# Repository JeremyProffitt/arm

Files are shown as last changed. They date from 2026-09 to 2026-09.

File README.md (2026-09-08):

# LUMA — printable robotic desk companion

<p align="center">
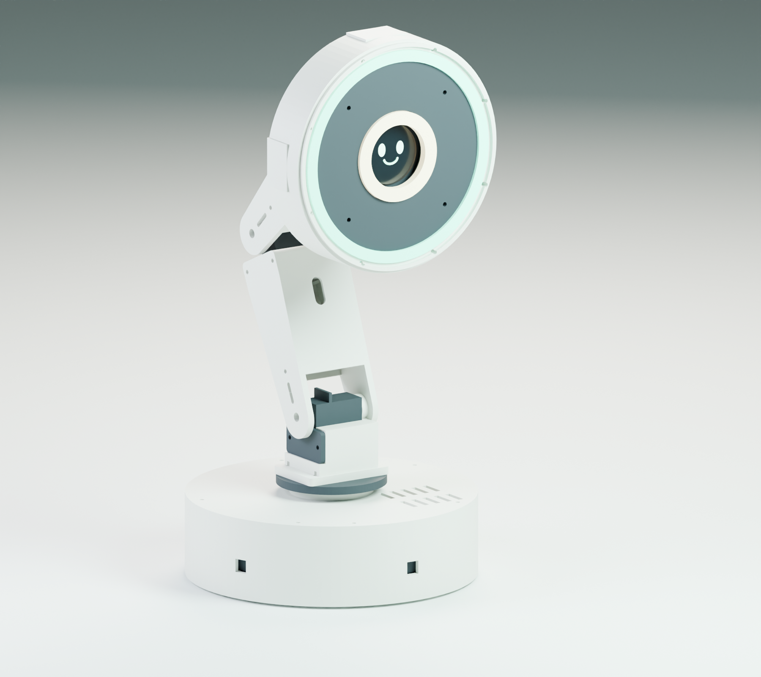
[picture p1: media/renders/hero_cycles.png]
LUMA robotic desk companion hero render
  
</p>

<p align="center"><em>A little light. A little motion. A lot of personality.</em></p>

Open [START_HERE.html](START_HERE.html) for the illustrated project browser and three promotional videos. The complete build reference is [LUMA_Assembly_Manual.pdf](deliverables/LUMA_Assembly_Manual.pdf).

This original prototype is inspired by the [Autonomous Lamp](https://www.autonomous.ai/lamp). It has a Raspberry Pi4 master, four inventory Miuzei DS3218MG joints controlled by a PCA9685, five Adafruit VL53L1X STEMMA QT sensors mounted inside the pedestal wall, a circular animated display, a white light ring, and a larger RGB halo.

Revision C (7 September 2026) moves all five sensors into direct four-screw mounts behind pedestal apertures. It replaces the former bus servos with the on-hand DS3218MG 270° units, widens the enclosed links for single-horn/625-bearing joints, and adds PCA9685 PWM plus a regulated6V servo rail. The standard head uses the **Waveshare ESP32-S3-Touch-LCD-1.85, SKU 28514**. The optional head uses the **Waveshare 4inch DSI LCD (C)** driven directly by the Pi.

## Meet LUMA

Click a scene to watch the full animation.

<p align="center">
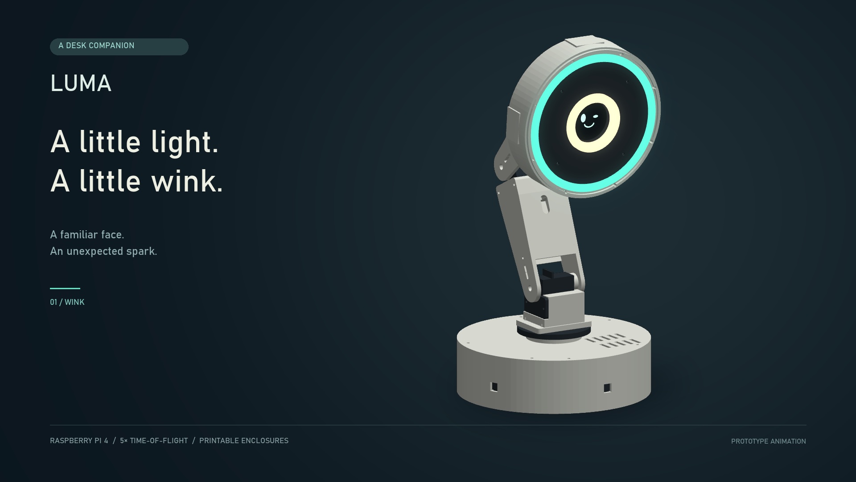
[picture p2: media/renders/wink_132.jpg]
LUMA winking
  
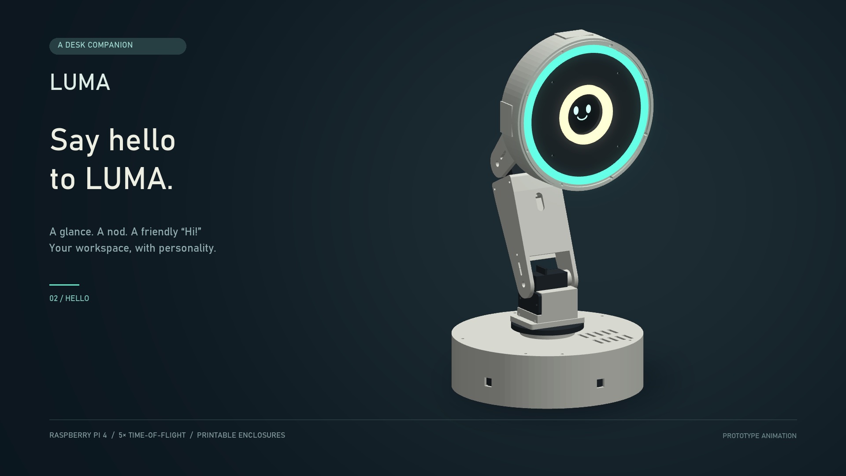
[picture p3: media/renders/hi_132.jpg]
LUMA saying hello
  
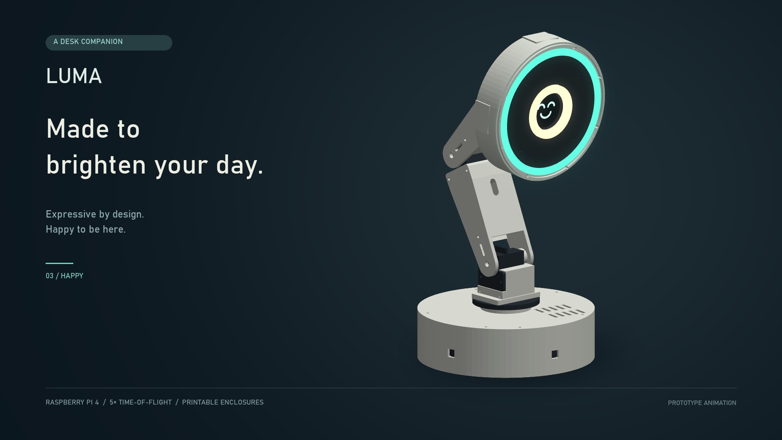
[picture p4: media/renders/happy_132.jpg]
LUMA showing a happy expression
  
</p>

<p align="center"><sub>Wink · Say hello · Happy</sub></p>

## Designed to be built

<p align="center">
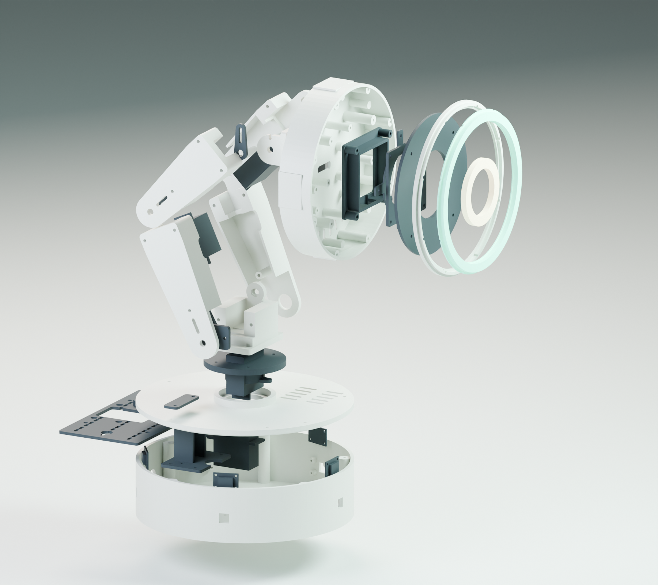
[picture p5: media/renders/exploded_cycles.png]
Exploded render of LUMA's printable structure and electronics
  
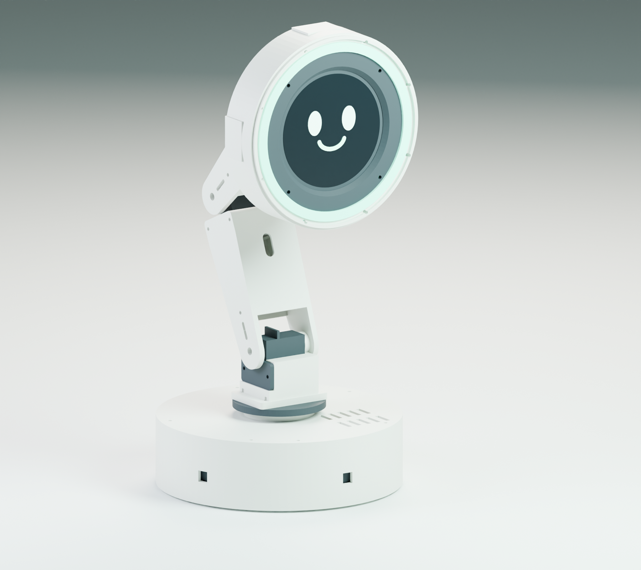
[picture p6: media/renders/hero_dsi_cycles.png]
LUMA with the optional four-inch DSI display head
  
</p>

<p align="center"><sub>Exploded standard assembly · Optional four-inch DSI display head</sub></p>

<p align="center">
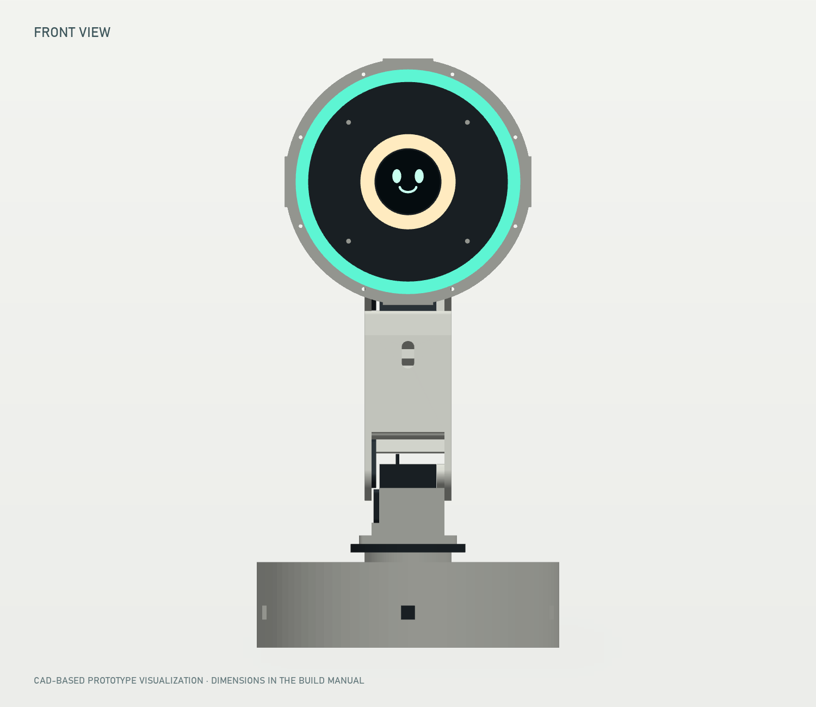
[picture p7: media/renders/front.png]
Front orthographic view of LUMA
  
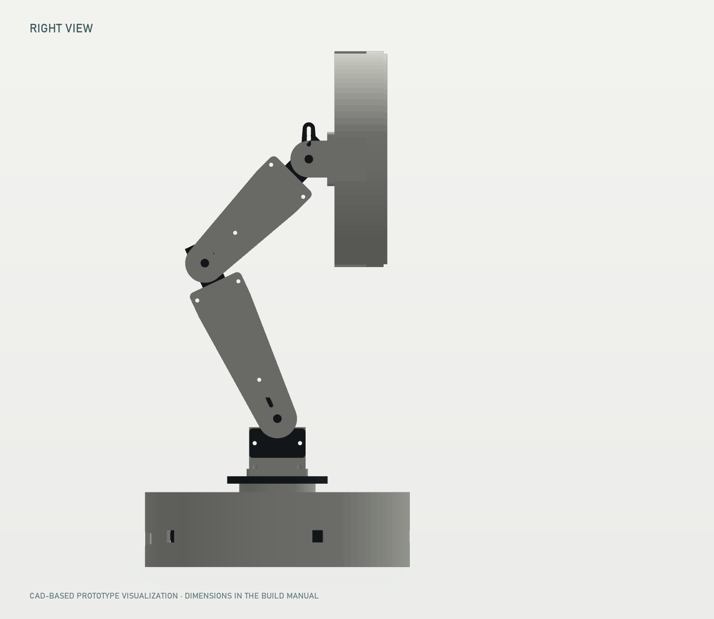
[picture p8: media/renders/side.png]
Right orthographic view of LUMA
  
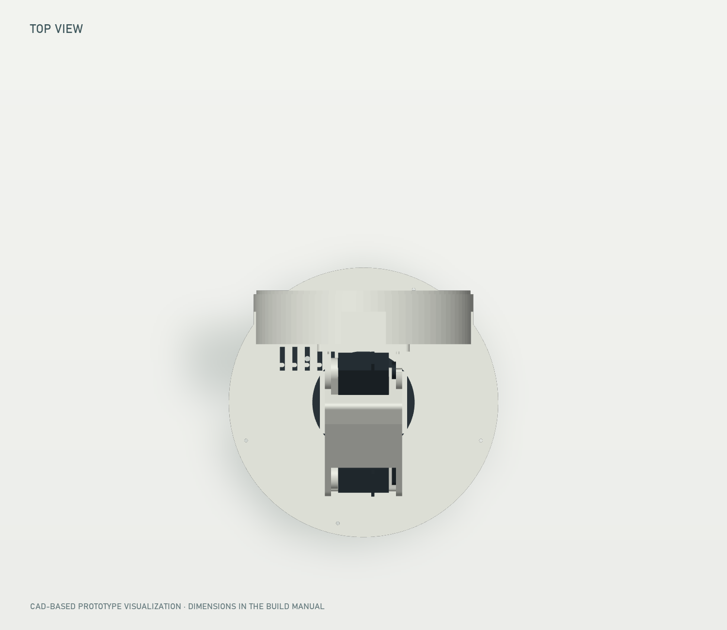
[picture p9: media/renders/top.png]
Top orthographic view of LUMA
  
</p>

## Deliverables

| File or folder | Contents |
| --- | --- |
| `deliverables/LUMA_Assembly_Manual.pdf` | Illustrated instructions, BOM, wiring, calibration, verification worksheet and engineering sheets |
| `deliverables/LUMA_Engineering_Drawings.pdf` | Standalone A3 drawing set, with model-derived views and interface dimensions, including the optional head sheet |
| `deliverables/LUMA_Purchased_Parts.csv` | Consolidated purchased parts, quantities, supplier links and budget allowances (`D` rows are the optional head) |
| `deliverables/LUMA_Print_Schedule.csv` | Printable part quantities, materials, orientations and variant (`standard` or `dsi-head`) |
| `cad/stl/` | Individual printable STL files, in millimeters |
| `cad/luma.scad`, `cad/build.py` | Editable parametric source and export script |
| `cad/assembly.scad`, `cad/assembly_dsi.scad` | Open in OpenSCAD for the complete assembled model, standard or optional head |
| `cad/assembly.json`, `cad/assembly_dsi.json` | Exact assembly placements, articulation axes and indexed neutral pose |
| `cad/ballast_plate.dxf`, `cad/ballast_plate.svg` | Steel ballast profile and dimensioned drilling template |
| `cad/visual_only/` | Purchased-component envelopes for visualization; do not print these |
| `electronics/` | Electrical architecture, wiring diagram, pin-to-pin CSV and source BOM |
| `software/` | Pi controller, simulation, tests, setup, exact-board face firmware and the Pi-rendered face for the DSI head |
| `media/videos/01_wink.mp4` | Winking promotional animation |
| `media/videos/02_hi.mp4` | Greeting promotional animation with spoken “Hi!” |
| `media/videos/03_happy.mp4` | Happy promotional animation |
| `media/renders/` | Finished, exploded, orthographic and promotional images, plus `hero_dsi.png` for the optional head |
| `media/sources/` | Editable rendering and animation sources |
| `validation/` | Mesh/intersection, software, PDF and video verification records |
| `plan.md` | Revision C work plan and execution log |

`deliverables/LUMA_Complete_Project.zip` is the portable archive. Extract it before opening the HTML index. Development tool downloads, virtual environments and intermediate previews are excluded. The archive contains a SHA-256 inventory.

`deliverables/LUMA_Printable_STLs.zip` is the smaller print-only download, including the quantity schedule and printing notes. Consult the assembly manual before printing or purchasing parts.

## Before printing

Read the mechanical assembly chapter and exact part list. Print the fit coupon first. The largest base parts have a 216 mm footprint, so a 220 mm bed needs careful placement and little or no brim; a larger bed provides more margin. Structural parts use PETG. Both light covers use natural translucent PETG, with a thin solid face that can be lightly frosted after printing. Each arm link is a left and a right half; print both, plate-down, and assemble the servo and harness inside before closing the link.

The initial folded pose reduces reach: upper link115° and forearm45° above+Y, head facing+Y. Center one unloaded DS3218 at a time before installing its horn. Motion commands are small offsets around this pose. The uncalibrated default does not arm the motors, and PCA9685 communication does not prove shaft position.

The full STL assemblies are for viewing. Print the individual files and apply the schedule quantities. Purchased bearings, metal servo horns, steel ballast, electronics and fasteners are not printed replacements. The optional4-inch head prints three variant files and omits six standard-head files; the schedule lists both sets.

## Run the simulator

Python 3.11 or newer is sufficient; no Pi hardware is activated:

```console
cd software
python -m luma.app --scene wink
python -m luma.app --scene hi
python -m luma.app --scene happy
python -m unittest discover -s tests -v
```

The simulator prints timestamped expression, light and pose events. The software README gives the separate Raspberry Pi installation, display firmware build, the optional DSI-head display setup and supported first-motion procedure.

## Rebuild documents and checks

Create a Python environment and install `docs/requirements.txt`. Install OpenSCAD for the CAD exports; consult `cad/build.py` and the mechanical notes for platform paths and selectors. The media README describes the video/rendering dependencies.

From the project root, once the CAD, media and source chapters are present:

```console
python cad/build.py
python cad/check_purchased_fit.py
python validation/check_assembly.py
python docs/build_bom.py
python media/sources/render_media.py --stills
python media/sources/render_media.py --manifest cad/assembly_dsi.json --suffix _dsi --stills --views hero
python docs/build_drawings.py
python docs/build_manual.py
python validation/verify_project.py
python docs/package_project.py
```

The static intersection check compares assembled printed solids at the indexed neutral pose for both assemblies. It does not certify the full motion envelope, purchased hardware fit, wiring clearance, strength, balance or temperature. The final verification report distinguishes executed digital checks from untested hardware and records the display cross-compilation status separately.

## Release status

Revision C is a digital prototype, not a physically built or certified product. The promotional clips are rendered animations. Physical horn/bearing fit, supported commissioning, load/stability checks, regulated6V behavior and thermal/optical measurements remain first-build work. The DS3218 servos provide no readable position/current/temperature feedback. No measured lumen/CRI output or autonomous collision-avoidance capability is claimed. The optional head's800mm DSI cable remains a bench-verification item.

Vendor specifications and third-party display initialization provenance are linked in the manual and firmware notices. The appearance-reference image used during research is not redistributed in the package.

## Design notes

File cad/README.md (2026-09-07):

# LUMA CAD files

Open `assembly.scad` in OpenSCAD to view the entire assembled lamp with the standard 1.85-inch head, or `assembly_dsi.scad` for the optional 4-inch DSI head. Both import the supplied meshes with the positions and colors in `assembly.json` / `assembly_dsi.json`; `assembly_preview.scad` is an equivalent copy of the standard preview. Edit individual part geometry in `luma.scad` and select its `part` parameter using an ID from `part_manifest.json`.

Print the standard build from the24 files in `stl/` whose manifest `variant` is `standard`, in the quantities from `part_manifest.json`. The optional4-inch DSI head adds `head_shell_dsi`, `lcd4_carrier` and `face_ring_dsi`, and omits `head_shell`, `face_center`, `white_carrier`, `inner_diffuser`, `lcd_cradle` and `lcd_retainer`. Revision C has no printable sensor pods, retainers or brow bracket: all five Adafruit3967 boards screw directly to bosses inside the pedestal wall. The four arm halves print plate-down, and the head fork prints on its mounting plate rotated180 degrees aboutX. Do not print anything from `visual_only/`; it contains purchased-component envelopes and complete assembled references.

The exact OpenSCAD executable location defaults to `C:/Program Files/OpenSCAD/openscad.com`; override it with the `OPENSCAD` environment variable if needed. Run `python cad/build.py` from the project root with NumPy and trimesh installed to regenerate every asset, or `python cad/build.py upper_arm_left forearm_left` to re-export only the named parts. The hidden electronics tray uses 32 facets to keep exports practical; all dimensions remain the same. `cad/refresh_validation.py` measures existing STLs without re-exporting them.

`ballast_plate.dxf` contains a 180 mm steel disc outline and eight drill circles in millimetres. Its thickness is 6 mm; the DXF is 2D, not an instruction to print the ballast. The dimensioned SVG drill template is on a 250 x 230 mm page, suitable for an actual-size A3 print.

`validation.json` records mesh integrity, connected bodies, dimensions and solid volume. `purchased_fit.json` checks conservative DS3218MG, pedestal-sensor and display envelopes in both assemblies; `../validation/assembly_check.json` records printed-part intersections at indexed neutral. These reports do not replace a physical horn/bearing fit, load, electrical, thermal or moving-clearance test.

`mechanical.md` provides the assembly instructions and assumptions. `bom_mechanical.csv` lists metal, three625 idler bearings, hardware and printing consumables. Rows starting with `D` belong to the optional head. The complete BOM also includes the inventory DS3218MG servos, user-selected PCA9685 and6V regulator. Vendor geometry sources are identified in `docs/sources.json`.

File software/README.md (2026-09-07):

# LUMA Pi4 controller and face firmware

The project includes a deterministic simulator and Raspberry Pi adapters for five pedestal ranging sensors, four Miuzei DS3218MG servos through a PCA9685, two independent LED rings, USB face display and local spoken Hi. The simulation needs Python3.11 or later.

```console
cd software
python -m luma.app --scene wink
python -m luma.app --scene hi
python -m luma.app --scene happy
python -m unittest discover -s tests -v
```

Simulation prints timestamped pose/light/face events as JSON. It advances deterministically without sleeping. `--seconds` sets duration. Scenes last6seconds, then return to idle. The three promotional scenes remain within the initial CAD travel envelope; they are repeatable face/motion scripts and do not require a cloud service.

## Raspberry Pi installation

Use Raspberry Pi OS Bookworm64bit on Pi4. The following setup commands affect only a Pi used for this project; do not execute them on the development Windows computer.

```console
sudo apt update
sudo apt install python3-venv python3-pip python3-dev i2c-tools espeak-ng alsa-utils
sudo raspi-config
```

In Interface Options enable I2C and SPI. In `/boot/firmware/config.txt`, confirm `dtparam=i2c_arm=on`, `dtparam=i2c_arm_baudrate=100000`, and `dtparam=spi=on`. Set `dtparam=audio=off` because BCM18's PWM peripheral drives theRGBW ring and analog audio conflicts. USB audio is separate. Reboot after these settings.

```console
cd software
python3 -m venv .venv
.venv/bin/pip install -e '.[hardware]'
ls -l /dev/serial/by-id/
aplay -l
```

Enter the actual display `/dev/serial/by-id/` path in `config.json`. The PCA9685 is I2C address64 (`0x40`), with yaw/shoulder/elbow/wrist on channels0/1/2/3. Select the USB speaker as the ALSA output or set `audio_device` to the identifier from `aplay -L`. The standard display and speaker share Pi4 USB power; use a powered hub if measurement requires it. Motors and LEDs never take power from Pi USB or GPIO.

Before connecting motor power, test the sensor chain and display independently. These commands do not instantiate the PCA9685 or LED drivers and do not require calibrated joints:

```console
.venv/bin/python -m luma.bench sensors --seconds 10
.venv/bin/python -m luma.bench display --port /dev/serial/by-id/YOUR_DISPLAY_DEVICE --scene all --seconds 10
```

The sensor check reports millimeters, age and mux channel in front/front-left/rear-left/rear-right/front-right order. Present a matte target at each pedestal aperture. `near` means a valid value below100mm: communication can pass, but armed motion would fault. The display check cycles idle/wink/Hi/happy and checks firmware replies. Inspect the pixels yourself. Exit status0 is pass,1 fail and130 interrupted. I2C normally needs membership in the `i2c` group; USB serial normally needs `dialout`.

Center only one disconnected, unloaded servo at a time. Keep its straight horn off the arm and keep the physical stop in reach. The command is capped at10seconds, disables the other three PCA9685 channels, and removes the selected PWM pulse when it exits:

```console
.venv/bin/python -m luma.bench servo --joint yaw --pulse-us 1500 --seconds 2 --confirm-unloaded
```

Repeat with `shoulder`, `elbow` and `wrist`. Power off before installing each horn. The DS3218 datasheet gives500-2500µs over270° with1500µs nominal neutral. Record the actual mechanical neutral in `neutral_pulse_us`; do not use this command on a loaded joint.

The PWM-backed NeoPixel library normally requires root on Pi4, so the full hardware command uses the virtual environment interpreter with sudo. Leave `calibrated=false` while wiring/testing. Hardware mode without `--arm` requires PCA9685 communication but leaves all four PWM outputs disabled; the separate6V motor rail can remain off.

```console
sudo .venv/bin/python -m luma.app --hardware --scene hi --seconds 6
```

Complete the commissioning procedure in `../electronics/architecture.md`, including unloaded neutral indexing, polarity/sign checks, physical stop tests and five valid pedestal ranges. Only then set `calibrated=true`. Support the arm in its indexed pose before every armed start; software cannot read its physical angles:

```console
sudo .venv/bin/python -m luma.app --hardware --arm --scene happy --seconds 6
```

Any fault latches for that process. It stops new targets and leaves the PCA9685 at the last pulse widths. Inspect the reason, support the arm, remove the cause and restart explicitly. PCA9685 health proves I2C communication only, not servo movement or position. The physical motor stop removes6V holding power. There is no unattended boot or auto-arm service.

## Display firmware

`display_firmware/` targets **ESP32-S3-Touch-LCD-1.85 SKU28514 only**. It uses USB serial115200, an ST77916 QSPI controller on CS21/SCK40/D046/D145/D242/D341, and a TCA9554 at0x20 over SDA11/SCL10 for LCD resetEXIO2/P1. Backlight is GPIO5. This pin mapping is from the [Waveshare board documentation](https://docs.waveshare.com/ESP32-S3-Touch-LCD-1.85) and schematic. Firmware reads panel register0x04 and chooses one of the exact two vendor initialization tables: ID00-7F-7F-7F or00-02-7F-7F. Unknown IDs produce an error and do not advertise READY. Register command/data/delay values were converted from the vendor's April2025 demo to [Arduino_GFX](https://github.com/moononournation/Arduino_GFX/tree/v1.6.5) operations. A successful compile does not prove physical display operation; verify the purchased panel on the bench.

Install PlatformIO and build/flash the connected board:

```console
python -m pip install platformio
cd display_firmware
python -m platformio run
python -m platformio run --target upload --upload-port YOUR_SERIAL_PORT
python -m platformio device monitor --port YOUR_SERIAL_PORT --baud 115200
```

Commands are newline-delimited ASCII. `PING` replies `PONG`. `FACE idle`, `FACE wink`, `FACE hi`, `FACE happy`, and `FACE fault` reply `OK <name>`. Startup announces `READY LUMA1`. Invalid or overlong commands reply `ERR`. After1.5seconds without a host command/heartbeat the display shows WAITING. The host sends heartbeat every250ms and latches a motion hold if replies stop. No touch/audio/SD/battery functions are enabled on the display board; speech is generated on the Pi and played by the USB speaker.

## Optional 4-inch DSI head (Pi-rendered face)

Instead of the ESP32 face board, LUMA can use a Waveshare 4inch DSI LCD (C) — a round720x720 panel wired directly to the Pi's DSI port. There is no coprocessor for this head: the Pi itself renders the face every frame with `luma/face.py`, which reproduces `paint()` from `display_firmware/src/main.cpp` in Python (same colors, same shapes, same scene timing) scaled from the firmware's360x360 canvas up to the panel's720x720 resolution.

Select this head by setting `"display_kind": "dsi"` in `config.json` (leave `display_port` alone; it is ignored for this kind). Install the extra dependency alongside the existing hardware group:

```console
.venv/bin/pip install -e '.[hardware,dsi]'
```

Add these lines to `/boot/firmware/config.txt` for the Waveshare4inch DSI LCD(C):

```
dtoverlay=WS_xinchDSI_Screen,SCREEN_type=10,I2C_bus=10
dtoverlay=WS_xinchDSI_Touch,I2C_bus=10
```

Both overlays are the vendor's documented setup; LUMA's software never reads touch events — the lamp has no touch-driven behavior. If the picture is upside down for the mounted orientation (connectors at the bottom), rotate it with the vendor's documented `display_lcd_rotate`/Wayland rotation setting rather than in LUMA.

Running outside a desktop session (the normal case for an unattended lamp) needs pygame's KMS/DRM backend. `sudo` drops environment variables, so pass the driver through `env`:

```console
sudo env SDL_VIDEODRIVER=kmsdrm .venv/bin/python -m luma.app --hardware --scene hi --seconds 6
```

Bench-check the head on its own, the same way as the USB face board:

```console
.venv/bin/python -m luma.bench display --kind dsi --scene all --seconds 10
```

`--port` is not required (and is ignored) when `--kind dsi`; it stays required for the default `--kind usb_serial`. There is no serial heartbeat to a coprocessor for this head, so `Hardware`/`bench.display`'s notion of "heartbeat" becomes "a frame was drawn within the last1.5seconds" — `DsiDisplay.update()` returns that boolean the same way `Display.update()` returns the USB PONG heartbeat, so the rest of the control/fault-latching logic in `luma/control.py` is unaffected by which head is attached.

## Source/verification notes

`luma/servo_pwm.py` uses the maintained Adafruit CircuitPython PCA9685 library at50Hz. It converts calibrated angles through the DS3218's documented500-2500µs/270° range, starts with all four outputs disabled, and checks controller registers over I2C. The bounded bench path enables one unloaded channel only. Tests cover the duty conversion, channel isolation, config validation, scene limits, five renamed sensor inputs and fault behavior. Hardware paths have not been exercised on a physical Pi/arm.

The pinned firmware toolchain is self-contained in `platformio.ini`; downloaded SDK/toolchain caches are development artifacts and do not need redistribution. Python hardware dependency versions are bounded for installation flexibility, not a physical acceptance-tested lockfile. Record actual installed versions with `pip freeze` when commissioning the Pi.

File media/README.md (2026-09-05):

# LUMA promotional media

Three 9-second films show the proposed lamp winking, greeting the viewer with an
audible “Hi!”, and moving happily. Each final MP4 is 1920 × 1080, H.264 with AAC
stereo sound and actual 24 fps CAD animation. A restrained camera push brings
each expression closer while keeping the titles stable.

These are **prototype animations**, not footage of a built or tested device.
All mechanical surfaces are rendered from the project's assembly STL files;
the screen graphics, illumination and motion are illustrative. No AI concept
images, stock footage, external music or unlicensed character assets are used.

## Rebuild

Install Python 3.13, Pillow, NumPy, ModernGL and imageio-ffmpeg. Generate the CAD
assembly first, then run from the project directory:

```powershell
python -m pip install -r media/requirements.txt
powershell -ExecutionPolicy Bypass -File media/sources/synthesize_hi.ps1
python media/sources/render_media.py --stills --clip all
```

The speech source uses the installed Windows Microsoft Zira Desktop voice.
The greeting WAV is included so rebuilding the films does not require Windows
speech synthesis. Original sound-design tones are synthesized by the renderer.

`sources/render_media.py` is the editable scene, camera, lighting, motion,
face-animation, typography and sound source. The assembly JSON supplies the
manufactured geometry and kinematic pivots. The final films use a depth-buffered
OpenGL renderer with 4× antialiasing. A basic software renderer is included as a
fallback. Blender is optional, via `sources/blender_stills.py`, for physically
lit still images.

The supplied hero and exploded `.blend` files use Blender 4.5.9 LTS. That optional
portable application was downloaded from the official Blender release archive
and verified against its published SHA-256 checksum. It is not included in the
project ZIP. Run `blender -b -P media/sources/blender_stills.py` to rebuild those
images, then use the resulting `*_cycles.png` files in the manual.

`renders/hero.png`, `exploded.png` and three orthographic PNGs support the PDF
manual. `renders/hero_dsi.png` shows the optional 4-inch DSI head; make it with
`python media/sources/render_media.py --manifest cad/assembly_dsi.json --suffix _dsi --stills --views hero`
(or `blender -b -P media/sources/blender_stills.py -- --manifest cad/assembly_dsi.json --suffix _dsi --hero-only`
for the physically lit version). The face graphics scale with the active display
radius in the assembly JSON. `renders/promotional_contact_sheet.jpg` samples the
films. `videos/` contains the deliverable MP4s; `audio/` contains the original and
mixed sound.

The `.tools/` directory, if present, is only a local dependency cache and is not
part of the design deliverables.

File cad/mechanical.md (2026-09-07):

# LUMA mechanical assembly, revision C

The editable geometry is `cad/luma.scad`. `cad/build.py` exports printable parts, two assembly manifests, purchased-part envelopes, and mesh measurements. Open `cad/assembly.scad` for the standard head or `cad/assembly_dsi.scad` for the optional4-inch DSI head. Files under `cad/visual_only` are not printable parts.

Revision C moves all five Adafruit3967 VL53L1X boards from external head pods to direct mounts behind the pedestal wall. It removes the pod, retainer, and DSI brow-bracket parts and closes the old head penetrations. It also replaces four dual-output ST3215 bus servos with four inventory Miuzei DS3218MG 270-degree PWM servos. The links and yoke are wider, each pitch joint has a625 bearing opposite its single driven horn, and the pedestal/yaw stack is6mm taller. Link pitches, indexed angles, displays, and light-ring geometry remain unchanged.

The indexed neutral has the upper link115° and forearm45° counterclockwise from forward+Y. The relative elbow angle is−70°. Pitch axes run alongX and yaw runs alongZ. Dimensions are: base diameter216mm and wall height56mm; shoulder axisZ121mm; upper pitch140mm; forearm pitch120mm; head diameter176mm and optical depth42mm. The rear head plane center is aboutY46.7mm/Z332.7mm, and the housing top is about420.7mm. Rubber feet add5mm.

## Purchased geometry and fit datums

The Miuzei DS3218 datasheet specifies a40 × 20 × 40.5mm body, 4.8-6.8V PWM control, and a300mm lead. The model uses a conservative body envelope fromX−30..10 relative to the shaft, Y±10, and Z−40.5..0 from the output-side case plane. The mounting-tab envelope is54.5mm long at the datasheet's27.7mm height datum. The included straight metal arm and25T spline stay purchased parts. Its attachment-hole positions and thread are not dimensioned, so the printed driven interfaces use a7mm center clearance and two3.4mm radial slots at12-18mm and20-25mm. Measure the actual horn before selecting bolts. Source: https://images-na.ssl-images-amazon.com/images/I/81Lbgu%2BnG6L.pdf .

Each pitch joint is supported on both sides. The driven plate attaches to the straight metal servo arm through a3.3mm printed spacer. The opposite plate carries a625-2RS bearing, 5mm bore ×16mm OD ×5mm wide. An M5 precision-shank or shoulder bolt clamps only the bearing inner race to a captive M5 nut in the parent idler boss. Use thin thrust washers that do not touch the outer race. The yaw platform remains independently supported by one6808-2RS bearing, 40 ×52 ×7mm.

The Adafruit3967 board outline and four plated holes come from Adafruit's Eagle board file. The board is25.40 ×17.78mm. Its2.5mm holes form a20.32 ×12.70mm pattern centered on the optical package. The pedestal uses four6mm bosses with2.1mm blind pilots per board. The board's component face points outward and its sensor looks through a10 ×10mm open wall aperture. Source: https://github.com/adafruit/Adafruit-VL53L1X-PCB .

The standard display remains the55 ×55mm Waveshare ESP32-S3-Touch-LCD-1.85. It uses a55.8mm edge pocket and foam shims; no guessed board holes. The optional Waveshare4inch DSI LCD(C) remains a round720 ×720 panel in aØ126mm case with four M4 bosses on a75 ×75mm square. Its controller-board/connector envelope is measured from the vendor STEP. Verify every purchased connector and glass projection before tightening.

## Print settings and fit coupon

Print all units in millimeters at100%. The216 ×216mm base leaves only2mm per edge on a220mm bed. Use PETG,0.20mm layers, four walls for general parts, and six walls/40% gyroid for the four link halves and joint supports. The link halves print with their5mm outer plates on the bed. The head yoke prints on its rear mounting plate, rotated180° aboutX, with supports under the fork ears. The removed sensor pods, retainers, and brow bracket are not part of revision C.

Print `fit_coupon` first. It carries3.0/3.2/3.4/3.6mm bores, the16.2mm 625 pocket, and the DS3218 straight-horn slots. Tune only the affected CAD clearance; never scale the full mechanism. A625 bearing must seat squarely without force through its inner race. Clear through-holes by hand. The2.1mm base sensor and Pi pilots are for carefully started M2.5 screws. Do not force a screw or bend a PCB.

Print the light diffusers in natural/translucent PETG at0.15mm layers, three perimeters, and100% infill. Preserve the1.2mm optical skin. Do not put printed plastic, frosting, adhesive, or an untested IR window over any ToF aperture.

## Prepare metal parts

1. Make theØ180 ×6mm mild-steel ballast from `cad/ballast_plate.dxf` or the dimensioned SVG. Drill fourØ4.4 holes at(±45,±35) and fourØ3.4 holes at(±26,−36/−8). Deburr and protect it from corrosion. Keep the center solid.
2. Confirm the6808 bearing is40 ×52 ×7mm and all three625 bearings are5 ×16 ×5mm. Test the printed pockets before assembly.
3. Inspect all four inventory DS3218MG units and straight25T arms. Confirm the servo is the270° position variant, not a continuous-rotation unit. Measure the metal-arm hole diameter, spacing, thickness, center-screw engagement, and clearance over the case. Dry-fit each printed radial slot before power is applied.
4. Test each M5 idler stack outside the arm. The smooth bolt section must span the bearing inner race. The washer and printed plate must not touch the rotating outer race. The captive nut must seat without splitting its boss.

## Assemble the pedestal sensors and weighted base

5. Put the steel disc on the3mm base floor. Attach the yaw cradle atZ9 with fourM3x16 bolts through the asymmetric pattern. Keep all underside hardware above the rubber-foot contact plane.
6. Identify front as+Y. The five sensor centers are front90°, front-left162°, rear-left234°, rear-right306°, and front-right18°. Insert oneM2.5x6 screw through each board hole from the PCB's inner side. Put the component face toward its wall opening and start all four screws into the matching blind pilots. Tighten in a cross pattern only until the board cannot rock. Confirm the optical package is centered and unobstructed. Connect one side STEMMA QT socket and strain-relieve the cable inside the wall.
7. Place the yaw DS3218MG with its shaft vertical, its body toward−Y, its case bottom atZ12, and its output-side case plane atZ52.5. The rear-body cradle avoids the servo's mounting ears. Fit the yaw keeper atZ52.5 with twoM3x50 bolts atX±18.5/Y−27. Tighten only enough to secure the case.
8. Mount the electronics tray atZ14 on four5mm metal spacers with fourM4x25 bolts through base, ballast, spacer, and tray. Mount the Pi on its standoffs. Use the universal tray slots for the PCA9685, sensor mux,6V regulator, and insulated distribution hardware; their exact board revisions are not assigned guessed hole coordinates. Keep the regulator ventilated. Keep the external AC adapter and any oversized high-current enclosure outside the compact base.
9. Use the round rear wall port at270° and rectangular port at282° for external power/USB. Add grommets and strain relief. The six lid posts sit at42/66/126/198/258/342° between the sensor sectors and rear ports.
10. Seat the6808 in the lid's52.15mm pocket. The turntable's39.75mm neck passes through its40mm bore. Below the lid, attach the3mm tangential horn web to the yaw servo's straight metal arm through the adjustable slots. The web stays below the lid disk and the neck carries load through the bearing. Verify free±25° yaw before fitting sixM3x12 lid screws. The turntable top and shoulder-tower datum areZ74.

## Assemble the shoulder and enclosed links

Each link has an idler half and a driven half. LocalX runs from proximal pivot to distal servo shaft:140mm for the upper link and120mm for the forearm. The5mm plates occupy assembled Z−31..−26 and+26..+31. Each half has26mm-deep walls that meet atZ0. The DS3218 rear-case pocket is41.2mm across the axis and20.7mm across the body. The walls start atX28, leaving the proximal clevis open. A21 ×9mm cable port remains on the inner wall. ThreeM3x70 bolts close each link: one atX35 and two around the distal block atY±18.5.

The idler half has a16.2mm bearing pocket at its proximal pivot and an M5 captive-nut boss at its distal servo axis. The driven half has the two straight-horn slots at its proximal pivot. The parent servo output-side case plane sits at localZ+20.25. Its metal arm and the3.3mm spacer fill the gap to the driven plate inner face atZ+26. The opposite case face clears the idler boss by0.35mm. These are digital nominal clearances and require a physical fit check.

11. Bolt the shoulder tower to the turntable with fourM3x16 bolts. Fit the shoulder DS3218MG with its shaft atZ121 and its output side toward the driven link half. Install the keeper with twoM3x60 bolts. Insert the first M5 captive nut into the tower idler boss before the upper link blocks access.
12. Press one625 bearing into the proximal pocket of `upper_arm_left`. Put the inner race against the shoulder idler boss with its thrust washers and M5 axle. Do not tighten the outer race. With the shoulder servo centered and unpowered, index the link at115° and attach `upper_arm_right` to the straight metal arm through one printed spacer and two measured horn fasteners.
13. Seat the elbow DS3218MG in the upper-link distal pocket with its shaft atX140. Put its output toward the driven half and cable toward the rear relief. Route its lead and the remaining head harness through the inner wall port. Insert the distal M5 captive nut. Close the two halves with threeM3x70 bolts without crushing the case.
14. Assemble the forearm the same way. Its idler625/M5 stack attaches at the elbow, and its driven half attaches to the elbow's straight horn at−70° relative angle. Seat the wrist servo atX120, route its lead, insert the last M5 captive nut, and close with threeM3x70 bolts.
15. The head yoke has one625 idler ear and one tangential straight-horn ear. Attach its bearing side to the forearm idler boss, then attach its driven side to the centered wrist horn through the last3.3mm spacer. At neutral, the broad head plate faces+Y and lies21mm forward of the wrist axis. Verify that the servo mounting tab clears the yoke notch.
16. Pass the head harness through the26 ×8mm yoke slot, over each servo case, and through both link ports. Leave a slack service loop at every joint. No moving wire may enter a horn, bearing, idler bolt, or clamshell seam.

## Assemble the standard 1.85-inch head

Head-localZ starts at the rear face and increases toward the viewer. The shell floor isZ0-3 and rim ends atZ36. There are no sensor mounts or apertures in the revision C head.

17. Attach `head_shell` to the yoke with fourM3x12 bolts on the54 ×30mm pattern. Bring only display, LED, and optional DSI wiring through the center slot.
18. Join four Adafruit1768 RGB quarter-rings into one60-pixel circle. Dry-fit the158mm OD/145mm ID board on the radius76 posts. Retain the PCB mechanically; solder bridges are electrical joints only.
19. Put the standard LCD cradle on its four headZ14 pillars. Place the55mm board in the55.8mm pocket with thin edge foam and its low-profile USB plug in the19mm relief. Fit the retainer atZ29 with fourM3x25 screws. Do not load the glass.
20. Fit the white-ring carrier on the radius45 bosses atZ32.5 with fourM3x10 screws. Attach the24-pixel RGBW ring without covering LEDs or loading solder joints.
21. Put1mm shims on the four radius60 face bosses and eight radius83 bezel bosses. Fit the outer diffuser, center baffle, and outer bezel without squeezing the optical skin. Secure the center with fourM3x12 and bezel with eightM3x10. Retain the inner diffuser with three small removable neutral-cure silicone dots.

## Assemble the optional 4-inch DSI head

This variant replaces `head_shell`, `face_center`, `white_carrier`, `inner_diffuser`, `lcd_cradle`, and `lcd_retainer` with `head_shell_dsi`, `lcd4_carrier`, and `face_ring_dsi`. It keeps the yoke, outer bezel, outer diffuser, and60-pixel halo. It has no brow bracket or head-mounted sensors and no separate white ring.

22. Attach `head_shell_dsi` to the yoke with fourM3x12 bolts. Fit the RGB halo on its radius76 posts.
23. Attach `lcd4_carrier` to the display's four M4 bosses with M4x8 screws. Do not use longer screws. Confirm the PCB, Pi standoffs, power connector, USB-C, and DSI FPC all clear the carrier window.
24. Lower the carrier onto the shell bosses at(±55,±38). Route the800mm DSI FPC and5V/GND lead through the26 ×8mm floor/yoke slots. Secure the carrier with fourM3x8 screws.
25. Put0.5mm foam on the display rim and1mm shims on the face/bezel bosses. Fit the outer diffuser, `face_ring_dsi`, and bezel. Tighten evenly without pressing the active glass. Configure and test the display before closing the base.

## Bring-up and limits

26. With every horn disconnected from the links, center one servo at a time using the bounded PCA9685 command in `software/README.md`. Mark its1500µs position. Power off before installing a horn. Set `neutral_pulse_us` and `joint_signs` from the actual indexed mechanism; the default values are not physical calibration.
27. Support the head and move each unpowered joint through the intended small range. Check the625 stacks, open clevises, servo tabs, cable loops, and straight horns. Initial commanded limits remain yaw±25° and shoulder/elbow/wrist±10° at12°/s. The supplied digital collision check covers only the indexed pose.
28. Verify the physical motor stop before armed motion. Run one joint and then one complete scene while supported. A PCA9685 check proves controller communication only. The DS3218 provides no position, current, load, or temperature feedback. Measure6V droop, regulator temperature, each accessible servo-case temperature, and joint holding behavior.
29. Recheck clamp, horn, idler, and link fasteners after the first short motion run and first thermal cycle. Stop on noise, binding, rising temperature, visible deflection, or lost PWM control. Physical fit, proof load, drop, fatigue, thermal, optical, and cable-flex tests remain first-build work.

## Load and stability calculations

The documented21.5kg-cm DS3218 stall torque at6.8V is about2.11N·m. Torque at the selected6V rail and continuous safe torque are not documented. Never treat stall torque as a holding-duty rating. A conservative folded standard-head estimate remains about0.40N·m at the shoulder; the optional DSI head estimate remains about0.48N·m. Wider link shells and actual wiring change mass, so weigh the build and repeat the calculation.

With a0.32m horizontal head moment arm, the standard0.40kg head alone produces about1.26N·m; the optional0.50kg head produces about1.57N·m, before link mass and acceleration. That is too close to the servo's6.8V stall rating for claimed continuous operation, and the project runs at6V. The restricted folded pose is deliberate. Reduce reach, add counterbalance, or change the actuator architecture before extended duty.

The1.19kg ballast alone gives a nominal1.26N·m restoring moment about the108mm base radius. This excludes dynamics, cable pulls, foot friction, and the raised center of mass. Use a commercial padded desk clamp if the measured build exceeds the validated stable envelope. This is not a lifting arm.

## Drawing and verification limits

Assembly matrices are row-major4×4 in millimeters. Right-side link halves are rotated180° about their length axis for assembly. Purchased horns, bearings, screws, wiring, and exact PCA9685 geometry are not printable substitutes. `validation/assembly_check.json` covers printable solids at the indexed pose. `cad/purchased_fit.json` covers conservative static DS3218, sensor-board, and display envelopes. Neither report certifies moving clearance, strength, electrical safety, or physical fit.

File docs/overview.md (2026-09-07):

# Meet LUMA

LUMA is a printable Raspberry Pi 4 desk companion with an articulated arm, a circular animated face and two independently controlled light rings. It is an original prototype inspired by the posture and personality of the Autonomous Lamp. It is not a conversion kit for the commercial lamp, and its parts do not claim compatibility with that product.

The head contains a Waveshare ESP32-S3-Touch-LCD-1.85 display, a small white-light ring and a larger RGB halo. The Raspberry Pi makes the behavior decisions. The ESP32-S3 built into the display serves as a graphics peripheral over USB. This preserves the requested Pi 4 control while using the actual QSPI display interface supported by the Waveshare board.

The selected 1.85-inch screen is a 360 × 360 IPS TFT LCD, not an OLED. Its visible circular area is approximately 45.68 mm across. Do not substitute a similarly named Waveshare B, C, AMOLED or bare display module without checking both the mechanical envelope and firmware pin mapping.

Revision C uses four matching on-hand Miuzei DS3218MG 270° servos through the user-selected PCA9685. Each wider enclosed link has a driven straight-horn side and an opposite625-bearing side. All five VL53L1X boards move from external head pods to direct mounts inside the fixed pedestal wall. The optional Waveshare4inch DSI LCD(C) head remains available, keeps the RGB halo, and has no separate white ring.

Optional 4-inch DSI head on the same base and enclosed arm.

## What the prototype does

- Wink: one eye closes briefly, the head makes a small gesture and the halo responds.
- Say Hi: a friendly greeting appears on the face, with an audible greeting through the specified audio hardware.
- Be happy: smiling eyes, a bright expression and a gentle arm gesture.
- Sense five horizontal pedestal sectors using Adafruit VL53L1X STEMMA QT boards on separate I2C multiplexer channels.
- Illuminate the face area with the white channel of a 24-pixel RGBW ring and express color with a separate 60-pixel RGB ring.

The provided behavior software runs locally. A conversational language model, camera, microphone, speech recognition and cloud account are not required by this design.

## What is in the project

The printable STL files and editable CAD define the mechanical prototype. The drawings in the back of this manual document those parts. The bill of materials identifies purchased hardware separately from printed parts. Wiring instructions and software source accompany the manual, along with three rendered promotional videos and their editable production scripts.

The project is a digital prototype release. Mesh and software checks can verify files and logic, but they cannot establish physical fit, holding torque, optical performance or print strength. The first assembled unit is the fit-and-function validation build. Record component revision, printer settings and any measured corrections before duplicating it.

## Design choices that matter during assembly

The 55 mm square display board cannot fit through the small light ring's roughly 52.2 mm center. It is installed behind that ring in a separate plane. Follow the head stack order instead of trying to place all boards side by side.

Each enclosed arm link clamps one DS3218 case between its halves. Its driven side uses the servo's straight metal arm, while a625 bearing supports the opposite side. Insert the captive M5 idler nut, servo, lead and harness before closing the three through bolts. The optional4-inch head mounts its display on a carrier plate attached to the display's M4 bosses.

The large RGB ring consists of four purchased 15-pixel quarter boards. Its printed support carries the mechanical load; the solder bridges only connect the electronics. All four arcs are needed to create the complete 60-pixel ring.

Frosted material belongs only over the light rings. Keep the LCD and five pedestal apertures open. A cover over a ranging sensor can create reflection and crosstalk.

The two NeoPixel rings use different pixel formats. The large ring is RGB and the small ring is RGBW. They use separate data outputs and separate driver objects. The normal brightness limits are part of the power and thermal design.

## Reading the drawings

All mechanical dimensions are in millimeters. STL files do not carry a unit declaration: select millimeters in the slicer and confirm the imported bounding dimensions before printing. Use the drawing's stated scale; page fitting in a PDF viewer changes paper scale. Numerical dimensions and the editable model control geometry.

Purchased circuit boards, bearings, fasteners and servo horns are not printable substitutes. Match the exact part numbers in the bill of materials. Minor manufacturing differences are handled by the stated clearances and the first fit coupon, not by forcing a board into a printed pocket.

## Build sequence

1. Check the purchased component revisions and inspect the dimensioned interfaces.
2. Print and measure the fit coupon, then slice the structural parts and diffusers.
3. Bench-test each electrical subsystem before fitting it into the arm.
4. Mount the five sensors inside the pedestal and assemble the base, joint supports and links with motors unpowered.
5. Assemble the layered head, display and light rings.
6. Route and restrain the wiring, leaving service loops at every moving joint.
7. Center each unloaded PWM servo, calibrate neutral pulses/signs and enable a restricted first movement.
8. Validate sensing, fault response, balance, temperature and the three expressions.

## Reference and attribution

The appearance reference is the [Autonomous Lamp](https://www.autonomous.ai/lamp). The LUMA geometry, manual layout and animations are newly authored for this project. Vendor specifications and documentation are identified in the component source register and bill of materials. Promotional files show the digital prototype, not a filmed or physically tested product.

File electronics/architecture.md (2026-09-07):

# LUMA electrical design, revision C

The Raspberry Pi 4 is the behavior and motion master. It reads five Adafruit 3967 VL53L1X STEMMA QT sensors through an I2C mux, commands four inventory Miuzei DS3218MG servos through the user-selected PCA9685 PWM board, selects face expressions, produces local speech, and drives both light rings.

The standard head uses the **Waveshare ESP32-S3-Touch-LCD-1.85, SKU 28514, without B or C suffix**. It is a 360 × 360 TFT LCD, not OLED. Its ESP32-S3 is a USB graphics peripheral; its Wi-Fi, touch, microphone, and battery functions are unused. Do not substitute a visually similar 1.85B, 1.85C, AMOLED, or bare panel. See [Waveshare documentation](https://docs.waveshare.com/ESP32-S3-Touch-LCD-1.85).

```
Pi4 USB ─┬─ Waveshare ESP32-S3 1.85 LCD / face firmware
         └─ USB speaker / local espeak-ng speech
Pi I2C ──┬─ PCA9685 address0x40 ─ PWM channels0..3 ─ four DS3218MG
         └─ PCA9548/TCA9548A-compatible mux address0x70 ─ ports0..4 ─ five VL53L1X
Pi BCM10 SPI MOSI ─ 74AHCT125 +330Ω ─ 60RGB outer ring
Pi BCM18 PWM0    ─ 74AHCT125 +330Ω ─ 24RGBW inner ring (white only)
Pi BCM27        ─ isolated NC stop contact ─ GND
12V relay output ─ 7.5A fuse ─ 6V/11A regulator ─ four fused servo feeds
```

## Optional 4-inch DSI head

The optional head replaces the USB display with a **Waveshare 4inch DSI LCD (C)**. It is a round 720 × 720 IPS panel in a 126 mm case. The Pi renders the face directly with `display_kind: "dsi"`; there is no display coprocessor or serial heartbeat. Connect its 15-pin 1.0 mm DSI FPC and connect 5 V/GND from Pi header pins4/39 to the display's HP2.0 socket. Leave that socket's SDA/SCL contacts empty. Touch and backlight control use `I2C_bus=10` on the DSI connector, and LUMA does not read touch input.

The FPC run through the arm is about800 mm. That is longer than the vendor-supplied50mm cables and must be proven on the bench before the links close. Keep it away from the moving 6 V servo feeds. This head omits the24-pixel RGBW ring; the outer halo supplies capped white output. [Vendor page](https://www.waveshare.com/4inch-dsi-lcd-c.htm).

## Power, stop, and servo distribution

Use the official Pi5.1 V/3 A USB-C supply. Use the external Mean Well GST220A12-R7B 12 V/15 A supply for the LED buck converter and the servo regulator. The enclosure contains DC only. All grounds meet at one DC star. Pi5 V and LED5 V remain separate. Wire the locking R7B connector exactly as its drawing specifies. [Mean Well specification](https://www.meanwell.com/Upload/PDF/GST220A/GST220A-SPEC.PDF).

The four Miuzei DS3218MG units are 4.8-6.8 V PWM position servos. The vendor datasheet gives 2.2 A stall current and21.5 kg-cm stall torque at6.8 V. Four can therefore demand8.8 A at once. This is an abnormal design transient, not a permitted continuous operating point. Use the Pololu D42V110F6 fixed6 V regulator. Its nominal rating is11 A, while its actual continuous output depends on input voltage, cooling, and load. Verify6 V polarity and loaded voltage before connecting a servo. [DS3218 datasheet](https://images-na.ssl-images-amazon.com/images/I/81Lbgu%2BnG6L.pdf), [regulator specification](https://www.pololu.com/product/5673).

A15 A main fuse protects the12 V trunk. A normally-open12 V relay interrupts only the servo regulator input. A latching stop's first NC contact interrupts the fused relay coil. Its second isolated NC contact grounds BCM27 in the normal state. Add the coil flyback diode with its stripe at coil positive. **The stop must remove servo power with the Pi disconnected.** Pi, display, sensing, and lights stay powered so they can report a stopped motor rail.

Feed the regulator through its own7.5 A time-delay fuse. Put a2200 µF/10 V or higher low-ESR capacitor across the6 V star. Feed each servo from that star through its own3 A time-delay fuse and18 AWG V+/GND pair. Do not send the possible8.8 A group current through a generic PCA9685 terminal block or PCB trace. At the PCA9685, connect only each servo's signal and ground; route V+ from the fused star. Confirm actual connector polarity instead of relying only on wire color.

Power PCA9685 VCC from Pi3.3 V. Connect SDA/SCL to Pi physical pins3/5, connect its ground to the DC star, and hold active-low `/OE` low. The PCA9685 address is0x40 and the sensor mux address is0x70. Software uses channels0,1,2,3 for yaw, shoulder, elbow, wrist at50 Hz. The documented DS3218 pulse range is500-2500 µs with1500 µs nominal neutral over the270-degree variant. The PWM board reports I2C communication only. It cannot report servo shaft position, load, current, or temperature. [PCA9685 guide](https://learn.adafruit.com/16-channel-pwm-servo-driver/hooking-it-up).

The Pololu D24V50F5 still converts12 V to the separate LED5 V rail through its2 A input and3 A output fuses. Software caps the outer RGB ring at20%. The outer ring allowance at that cap is about0.72 A. The inner ring uses RGB=0 and W no higher than192/255, about0.36 A. Put a1000 µF/10 V capacitor at each ring and a100 nF ceramic at the74AHCT125. Exact current and temperature require measurement.

## Five pedestal sensors and I2C allocation

All five Adafruit3967 boards mount behind open apertures in the216 mm pedestal wall. Looking down with the face aimed toward+Y, their centers are front90°, front-left162°, rear-left234°, rear-right306°, and front-right18°. Mux ports0 through4 use that same order. The two rear sectors can request a wink. The two front-side sectors can request the happy gesture. Every sector is also a mandatory obstruction input.

Each board remains at address0x29 on its own mux channel. The mux is the Adafruit5626 PCA9548, which uses the TCA9548A-compatible driver. Both the mux and PCA9685 share the upstream Pi I2C bus at3.3 V logic. Put the mux on the electronics tray in the pedestal. The five branch cables now remain in the fixed base and do not pass through yaw or the arm.

Software ranges only one emitter at a time with a33 ms short-mode timing budget. A normal five-channel sweep is about0.25-0.4 seconds. A missing sensor, invalid/no-return value, reading older than650 ms, or valid range below100 mm latches a motion hold. The five narrow horizontal cones do not cover every pinch point and are not a safety-rated perimeter.

Remove each shipping film. Keep every10 × 10 mm wall aperture open; no frosted plastic or uncharacterized IR window belongs in front of the sensor. Mount each25.40 × 17.78 mm board component-side toward its opening using fourM2.5x6 screws on its20.32 × 12.70 mm hole pattern. Tighten only until the PCB is stable. Leave side clearance for one STEMMA QT plug and add strain relief inside the base.

## Motion indexing without joint feedback

The DS3218MG has one25T output spline and no readable position channel. Yaw remains supported by the6808 bearing. Each pitch joint uses the servo's straight metal arm on the driven side and a625 bearing/M5 axle on the opposite side. The supplied metal arm's attachment holes are not dimensioned in the datasheet, so the printed interface has two radial slots. Measure each actual horn and select fasteners before applying load.

Center each disconnected, unloaded servo at1500 µs before installing its horn. The mechanical neutral pose is upper link115° from+Y horizontal, forearm45° from+Y, relative elbow−70°, and face vertical toward+Y. The shoulder axis isZ121 mm after the6 mm pedestal increase. Initial command limits remain yaw±25° and shoulder/elbow/wrist±10°. Calibrate each `neutral_pulse_us` and `joint_signs` value from the real mechanism; all1500/all+1 values are only starting values.

Hardware motion stays off unless both `calibrated=true` and `--arm` are supplied. Arming verifies fresh sensor data, display health, a closed motor stop, and PCA9685 communication, then sends the four calibrated neutral pulses. It cannot verify the physical starting angles. Support the complete arm before arming because a wrong pulse or horn index can cause immediate motion.

A behavior fault stops target updates and leaves the PCA9685 at its last commanded pulse widths. A PCA9685 I2C failure also stops new commands, but the controller or servo can retain its last output. Use the independent physical motor stop for unexpected motion. A motor-power cut releases holding torque. No software watchdog, encoder feedback, current feedback, thermal feedback, or safety-rated stop controller is claimed.

## Bench commissioning sequence

1. Keep all four horns disconnected from the links. Open the motor stop. Verify12 V input, LED5 V, Pi3.3 V logic, and the regulated6 V servo output separately. Confirm the2200 µF capacitor polarity.
2. With servo V+ still disconnected, run `i2cdetect -y 1`. Confirm PCA9685 at0x40 and the mux at0x70. Check every PCA9685 signal lead and all five mux branches against `wiring.csv`.
3. Test the five sensors with `.venv/bin/python -m luma.bench sensors --seconds 10`. Cover one pedestal aperture at a time and confirm the reported port/name order.
4. Connect one unloaded servo and one3 A fused branch. With the stop in reach, run `.venv/bin/python -m luma.bench servo --joint yaw --pulse-us 1500 --seconds 2 --confirm-unloaded`, changing `--joint` for each channel. The command disables the other three PWM channels and removes the selected PWM pulse when the bounded check ends. Mark the resulting physical neutral.
5. Power off. Fit each straight metal arm to its indexed servo. Dry-fit its two printed radial slots and the opposite625/M5 support. Confirm free rotation, bearing alignment, smooth-shank contact at the inner race, and no bolt contact with the servo case.
6. Test the standard or DSI display and both LED rings. Verify that outer RGB is at20% or less and inner W is at192/255 or less. Measure LED, regulator, Pi, and enclosure temperatures during a30-minute run.
7. Verify that the physical stop removes voltage at the6 V star with the Pi unplugged. Verify BCM27 reports stop when either NC2 wire is removed. Reset only while the head is supported.
8. Enter measured neutral pulses and joint signs in `config.json`. Set `calibrated=true` only after every unloaded joint moves in the correct direction. Run hardware mode without `--arm`, then one supported6-second scene with `--arm`.
9. Check the complete limited motion for cable clearance, collision, stability, servo/regulator temperature, and loaded6 V droop. Reduce travel or redesign the counterbalance if any joint cannot sustain the pose.

## Evidence and limits

Host behavior and PWM-conversion tests run without hardware. The CAD uses the vendor's body envelope and the Adafruit board's published mounting coordinates. Physical servo fit, horn-hole fit, PCA9685 board revision, regulator cooling, electrical continuity, holding torque, optical range, and thermal behavior remain first-build checks. Budget figures are planning allowances, not quotations.

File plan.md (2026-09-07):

# LUMA revision C - pedestal sensors and inventory servos

Single source of truth for revision C. A fresh run must be able to resume from this file alone.

Repository root: `C:\dev\arm`.
Branch: `main`.
Python: `C:\dev\arm\.venv\Scripts\python.exe` (3.13.14).
OpenSCAD: `C:\Program Files\OpenSCAD\openscad.com` (2021.01).
The repository has no Git remote, so this run commits locally and records that no push target exists.

## Locked decisions (user-confirmed; do not revisit)

- 2026-09-07 - user: "a number of things to fix and update, add holes for the VL53L1X adafuit board and mounting holes on the inside of the base to mount them.  change out the servos for the ones listed in inventory."
- 2026-09-07 - user: "yes, the peddestal.  all 5 sensors should be in the wall"
- 2026-09-07 - user: "use this board for pwm PCA9685"
- 2026-09-07 - available positional-servo inventory includes eight `Miuzei DS3218MG` 20 kg digital servos with 270-degree control. The other listed inventory consists of two continuous-rotation `SPT5525LV-360`, four `MG996R`, four 180-degree `MG995`, and fifteen `SG90` servos.
- Existing revision B decisions remain in force unless revision C explicitly changes them. Revision B is committed at `205a69b`.

## Design decisions taken by the run (defaults; report at completion)

- Use four matching Miuzei DS3218MG 270-degree positional servos, one for yaw, shoulder, elbow, and wrist. Do not use the continuous-rotation SPT5525LV-360 units because the joints require commanded positions. Do not mix MG995, MG996R, or SG90 units into the four-axis chain.
- Use the user-selected PCA9685 board at I2C address `0x40`, upstream of the existing TCA9548A-compatible sensor mux at `0x70`. Use channels 0 through 3 for yaw through wrist and 50 Hz PWM.
- Replace the 12 V ST3215 motor rail with a regulated 6 V rail. Four DS3218 units have a documented combined stall current of 8.8 A at 6.8 V; specify a 6 V regulator with at least 10 A continuous capability and retain one fused branch per servo. The existing 12 V external supply remains the upstream source.
- The PCA9685 controls pulse position but provides no joint-position, current, or temperature feedback. Software must fail on PCA9685 communication errors and must not claim physical feedback. Physical commissioning must use supported motion, measured PWM calibration, restricted travel, the existing independent motor-power stop, and visual checks.
- Put all five sensor boards behind the 216 mm pedestal wall. Use five equal 72-degree sectors, with the front sensor centered at `+Y`: front at 90 degrees, front-left at 162, rear-left at 234, rear-right at 306, and front-right at 18. This leaves the rear center at 270 degrees clear for the two existing cable ports.
- Each Adafruit 3967 board mounts directly to four internal bosses through its documented 2.5 mm holes on a 20.32 x 12.70 mm pattern. The board outline is 25.40 x 17.78 mm. Each wall position gets one open optical aperture; no printed optical window is used.
- Remove the external head sensor pods, their retainers, the DSI brow bracket, and all obsolete head pod holes. The existing head/display/light variants and arm pivot pitches remain otherwise unchanged.
- Raise the pedestal wall and yaw stack by 6 mm so the 40.5 mm DS3218 case clears the ballast and lid. The shoulder axis moves from Z115 to Z121; the 140 mm and 120 mm linkage pitches and indexed angles do not change.
- Support the three pitch joints on both sides. The driven side uses the supplied straight 25T servo arm through two adjustable radial slots. The opposite side uses a 625-2RS bearing, M5 axle bolt, and captive M5 nut. Widen the fork and enclosed links from 44 mm to 52 mm between plates to clear the DS3218 case and idler hardware.
- Rename the five physical channels to `front`, `front_left`, `rear_left`, `rear_right`, and `front_right`. The rear gesture uses either rear sensor. The side gesture uses either front-side sensor. All five remain mandatory obstruction inputs.
- Revision label becomes `Rev C / 07 Sep 2026` in source and generated deliverables.

## Verified facts

- 2026-09-07 - `git status --short --branch` returned only `## main`; the worktree was clean before revision C.
- 2026-09-07 - `git remote -v` returned no rows. There is no configured push or CI target.
- 2026-09-07 - drive C had 289,149,521,920 free bytes before work began.
- 2026-09-07 - the Miuzei DS3218 product datasheet at `https://images-na.ssl-images-amazon.com/images/I/81Lbgu%2BnG6L.pdf` specifies a 40 x 20 x 40.5 mm body, 4.8-6.8 V operation, 18 kg-cm and 1.8 A stall at 5 V, 21.5 kg-cm and 2.2 A stall at 6.8 V, 500-2500 us PWM, 1500 us neutral, 50-330 Hz, and a 180- or 270-degree variant.
- 2026-09-07 - the official Adafruit Eagle board file `Adafruit VL53L1X.brd` at `https://github.com/adafruit/Adafruit-VL53L1X-PCB` defines a 25.40 x 17.78 mm rounded board and four plated 2.5 mm mounting holes at `(2.54,2.54)`, `(22.86,2.54)`, `(2.54,15.24)`, and `(22.86,15.24)`, giving a 20.32 x 12.70 mm pattern centered on the board.
- 2026-09-07 - Adafruit documents the PCA9685 as a 16-channel I2C PWM controller and requires separate servo V+ power. The board logic supply does not power the servos. Source: `https://learn.adafruit.com/16-channel-pwm-servo-driver/hooking-it-up`.
- 2026-09-07 - Pololu D42V110F6 item 5673 is a documented 6 V, nominal 11 A regulator with a 6-60 V input range. Source: `https://www.pololu.com/product/5673`.
- Revision B uses external printable `sensor_pod` and `sensor_retainer` parts, head-shell pod holes, a DSI `brow_bracket`, four Waveshare ST3215 serial bus servos, and `software/luma/servo_bus.py`. These paths are replaced, not retained in parallel.
- Revision B checks passed at commit `205a69b`: 34 host tests, watertight printable meshes, and zero indexed-pose printed-part intersections for both head variants.

## Preconditions

- [x] Repository, branch, worktree state, disk space, Python, and OpenSCAD were checked with non-interactive commands.
- [x] Primary-source dimensions for the Adafruit sensor board and Miuzei servo were checked.
- [x] The operator selected the PCA9685 and confirmed all five sensors belong in the pedestal wall.
- [x] No deployment, external audience, destructive data operation, or scheduled automation is part of this run.

## Stop conditions (only these)

- An OpenSCAD export for a changed part fails deterministically after three geometry corrections.
- The new single-output servo joints cannot be given a mechanically supported opposite-side pivot without changing the locked linkage pitches or head interface.
- Required credentials or an external resource become necessary. There is currently no remote, deployment, or hardware bench in scope.

All other failures are classified, changed before retry, capped as stated below, recorded in the execution log, and worked around while independent work continues.

## Workstreams

### sensor-relocation - five direct-mounted boards in the pedestal wall

- [x] pedestal-geometry - Add five wall apertures and four internal M2.5 pilot bosses per board to `C:\dev\arm\cad\luma.scad`; remove conflicting wall vents while preserving lid ventilation and rear cable ports. Remove head pod apertures and obsolete pod/bracket parts. Proof command: `Set-Location 'C:\dev\arm'; & 'C:\dev\arm\.venv\Scripts\python.exe' 'C:\dev\arm\cad\build.py' base_tub head_shell face_center head_shell_dsi`; pass is exit0 with each row ending `True 1` and `Failures: []`.
- [x] sensor-assembly - Place five visual-only board envelopes behind the pedestal wall in both assembly manifests and remove all head pod instances. Proof commands: `Set-Location 'C:\dev\arm'; & 'C:\dev\arm\.venv\Scripts\python.exe' 'C:\dev\arm\cad\check_purchased_fit.py'` and `Set-Location 'C:\dev\arm'; & 'C:\dev\arm\.venv\Scripts\python.exe' 'C:\dev\arm\validation\check_assembly.py'`; pass is exit0, empty purchased intersections, and zero overlaps for both assemblies.
- [x] sensor-docs - Update CAD, electronics, wiring, software channel names, assembly instructions, and validation text for the five perimeter directions. Proof command: `& 'C:\dev\arm\.venv\Scripts\python.exe' -c "import json; from pathlib import Path; r=Path(r'C:\dev\arm'); a=[json.loads((r/'cad'/n).read_text()) for n in ('assembly.json','assembly_dsi.json')]; assert all(sum('Adafruit 3967' in p['name'] and p['group']=='base' for p in x['parts'])==5 and not any('ToF' in p['name'] and p['group']=='head' for p in x['parts']) for x in a); assert 'TOF_DOWN' not in (r/'electronics/wiring.csv').read_text(); print('sensor routes OK')"`; pass is exit0 and `sensor routes OK`.

### inventory-servo-conversion - four DS3218MG joints controlled by PCA9685

- [x] servo-mechanics - Replace ST3215 body clamps, dual-horn assumptions, horn interfaces, and purchased envelopes with DS3218 geometry plus an opposite-side supported pivot for each pitch joint; keep the existing6808-supported yaw. Proof commands: `Set-Location 'C:\dev\arm'; & 'C:\dev\arm\.venv\Scripts\python.exe' 'C:\dev\arm\cad\build.py' yaw_mount turntable shoulder_tower upper_arm_left upper_arm_right forearm_left forearm_right horn_spacer head_yoke fit_coupon`, followed by the two absolute-path fit commands in `sensor-assembly`; pass is exit0, `Failures: []`, empty purchased intersections, and zero printed overlaps.
- [x] servo-electronics - Replace ST3215/Bus Adapter A rows and12V motor branches with four inventory DS3218MG units, PCA9685 control, regulated6V power, branch fusing, and bulk capacitance. Proof command: `& 'C:\dev\arm\.venv\Scripts\python.exe' -c "from pathlib import Path; r=Path(r'C:\dev\arm'); t=(r/'electronics/bom_electronics.csv').read_text()+(r/'electronics/wiring.csv').read_text(); assert all(x in t for x in ('DS3218MG','PCA9685','D42V110F6','2200uF')); assert all(x not in t for x in ('ST3215','Bus Servo Adapter','USB data cable matching adapter')); print('servo electrical routes OK')"`; pass is exit0 and `servo electrical routes OK`.
- [x] servo-software - Replace the serial bus driver with a PCA9685 PWM driver; use config-defined channels, calibrated neutral pulses, pulse limits and angle span; report controller communication health without claiming servo feedback. Proof command: `Set-Location 'C:\dev\arm\software'; & 'C:\dev\arm\.venv\Scripts\python.exe' -m unittest discover -s 'C:\dev\arm\software\tests' -v`; pass is exit0 with38 tests and `OK`.

### release-regeneration - revision C user-facing artifacts

Depends on both workstreams above.

- [x] cad-release - Run the full CAD build and both geometry checks. Retry policy: correct deterministic geometry before rerun, with at most three focused corrections per changed part. Proof commands: `Set-Location 'C:\dev\arm'; & 'C:\dev\arm\.venv\Scripts\python.exe' 'C:\dev\arm\cad\build.py'`; `& 'C:\dev\arm\.venv\Scripts\python.exe' 'C:\dev\arm\cad\check_purchased_fit.py'`; `& 'C:\dev\arm\.venv\Scripts\python.exe' 'C:\dev\arm\validation\check_assembly.py'`. Pass is three exit0 results, `Failures: []`, empty purchased intersections and zero printed overlaps.
- [x] media-release - Regenerate standard/DSI stills and three clips. Watcher/restart policy: each foreground command reports failure or success; retry once only after a deterministic fix or one transient renderer failure. Proof command: `Set-Location 'C:\dev\arm'; & 'C:\dev\arm\.venv\Scripts\python.exe' 'C:\dev\arm\media\sources\validate_media.py'`; pass is exit0 with `films: 3`, `all_decoded: true`, and `stills: 13`. Visual proof paths are `C:\dev\arm\media\renders\hero.png`, `C:\dev\arm\media\renders\exploded.png`, and `C:\dev\arm\media\renders\hero_dsi.png`.
- [x] document-release - Regenerate BOM,32-sheet drawings,67-page manual, index and report with revision C labels. Proof command: `Set-Location 'C:\dev\arm'; & 'C:\dev\arm\.venv\Scripts\python.exe' 'C:\dev\arm\validation\verify_project.py'`; pass is exit0 and `"failures": []` with no outside-page text or empty pages.
- [x] package-release - Rebuild both archives and hash inventory. Proof commands: `Set-Location 'C:\dev\arm'; & 'C:\dev\arm\.venv\Scripts\python.exe' 'C:\dev\arm\docs\package_project.py'` and `& 'C:\dev\arm\.venv\Scripts\python.exe' -c "import zipfile; from pathlib import Path; r=Path(r'C:\dev\arm\deliverables'); assert all(zipfile.ZipFile(r/n).testzip() is None for n in ('LUMA_Complete_Project.zip','LUMA_Printable_STLs.zip')); print('ZIP integrity OK')"`; pass is two exit0 results and `ZIP integrity OK`.
- [x] review-release - Run the code-review skill against revision B commit`205a69b`, fix in-scope findings, rerun focused verification, commit only revision C files and attempt push only if a remote appears. Proof commands: `Set-Location 'C:\dev\arm'; git rev-parse '205a69b'; git log '205a69b..HEAD' --oneline; git status --short; git remote -v`. Pass requires resolved SHA`205a69b455f2d38dfe662a66e11844e351e2743d`, recorded two-axis review, empty status, and either a successful push or empty remote output recorded in the execution log.

## Execution log

- 2026-09-07 - Read the implementation skill. It requires focused tests, a final full test run, code review, and a commit.
- 2026-09-07 - Inspected `plan.md`, CAD source/build/fit checks, assembly checks, BOM and wiring sources, controller/config/tests, document generators, current renders, and revision B history. Confirmed the revision B implementation uses external head pods and ST3215 serial bus servos.
- 2026-09-07 - Verified clean `main`, no Git remote, Python 3.13.14, OpenSCAD 2021.01, and 289,149,521,920 bytes free on drive C.
- 2026-09-07 - Read the official Adafruit Eagle board geometry and Miuzei DS3218 datasheet. Selected four matching DS3218MG units and direct four-hole sensor mounting as the minimum coherent use of the confirmed inventory.
- 2026-09-07 - User confirmed the 216 mm pedestal, all five sensors in its wall, and PCA9685 PWM control. Revision C plan started.
- 2026-09-07 - Focused sensor exports: `python cad/build.py base_tub head_shell face_center head_shell_dsi` returned `Failures: []`; all four changed meshes were watertight single bodies. A rendered base preview exposed conflicts with a lid post and rear rectangular port. Moved lid posts to 42/66/126/198/258/342 degrees and grouped the cable ports at 270/282 degrees. `python cad/build.py base_tub base_lid` then returned `Failures: []`.
- 2026-09-07 - Replaced the ST3215 dual-output geometry with four DS3218MG envelopes, straight-horn slots on the driven sides, and 625/M5 idler interfaces on the opposite sides. Raised the base/yaw stack 6 mm and widened the pitch-joint plate spacing to 52 mm. The first complete check identified five deterministic placement/clearance errors. Corrected the turntable web height/shape, shoulder flange and keeper clearances, wrist tab notch, and head-spacer orientation.
- 2026-09-07 - Focused final CAD checks: `python cad/build.py head_yoke horn_spacer` returned both parts `True 1` and `Failures: []`; `python cad/check_purchased_fit.py` returned empty intersection lists for `standard` and `dsi_head`; `python validation/check_assembly.py` returned `standard: 24 instances, 0 overlaps above0.5mm3; dsi_head: 21 instances, 0 overlaps above0.5mm3`.
- 2026-09-07 - CAD milestone committed as `6dae64b` (`Move sensors to pedestal and fit DS3218 joints`). Retired `sensor_pod`, `sensor_retainer`, `brow_bracket`, and `servo_envelope` artifacts were removed; new DS3218 and Adafruit 3967 visual envelopes were committed.
- 2026-09-07 - Replaced `software/luma/servo_bus.py` with `software/luma/servo_pwm.py`. PCA9685 channels0-3 start with PWM disabled, use50Hz, convert the documented500-2500us/270-degree range, hold the last command on a behavior fault, and expose only controller communication health. Config now uses address64, channels0-3, and four calibrated neutral pulse widths. Sensor channels are `front`, `front_left`, `rear_left`, `rear_right`, `front_right`; rear and side gestures use their paired sectors.
- 2026-09-07 - Software verification: focused `python -m unittest tests.test_control tests.test_bench -v` passed19 tests. The first full run found two stale revision B fixtures in `test_face.py`; after updating those fixtures, `python -m unittest discover -s tests -v` passed35 tests in0.191s.
- 2026-09-07 - Added a bounded `luma.bench servo` path for centering one disconnected, unloaded DS3218MG. It requires `--confirm-unloaded`, caps duration at10s, disables the other three channels and removes PWM on exit. Added two focused tests; the full suite now passes37 tests in0.280s. Installed and imported `adafruit-circuitpython-pca9685`3.4.22 in the untracked development virtual environment to verify the declared dependency resolves.
- 2026-09-07 - Replaced live electrical and mechanical instructions with the PCA9685/DS3218/6V design. The motor relay feeds a7.5A input fuse, Pololu D42V110F6,2200uF capacitor and four3A branches; PCA9685 carries signal/ground only. Added three625 bearing/M5 idler stacks and20 M2.5 pedestal sensor screws. `python docs/build_bom.py` returned `80 purchase lines, $750.07 standard + $60.80 optional DSI head; 24 standard and 3 optional printable types`; standard print quantity is31.
- 2026-09-07 - Updated revision C README, project index, overview, printing, first-build validation, CAD assembly, software commissioning, source register, drawing/manual generators, wiring SVG and final/package revision metadata. CSV, JSON and SVG sources parsed successfully; `python -m luma.bench --help` lists `sensors`, `display`, and `servo`.
- 2026-09-07 - Full `python cad/build.py` exported all27 printable types as watertight single bodies and returned `Failures: []`. `python cad/check_purchased_fit.py` returned no intersections for either assembly. `python validation/check_assembly.py` returned `standard: 24 instances, 0 overlaps above0.5mm3; dsi_head: 21 instances, 0 overlaps above0.5mm3`.
- 2026-09-07 - Regenerated five standard and five DSI GL stills, then all three9-second clips. `python media/sources/validate_media.py` returned `films: 3`, `all_decoded: true`, `stills: 13`. Regenerated `hero_cycles.png`, `exploded_cycles.png`, and `hero_dsi_cycles.png` with Blender4.5.9; visual inspection confirmed clean heads, DS3218 envelopes and pedestal apertures. Copied the Cycles images to the manual hero/exploded targets.
- 2026-09-07 - `python docs/build_drawings.py` produced32 vector sheets; visual inspection covered G01, G03, E01, P01 and P09. `python docs/build_manual.py` produced67 pages. `python validation/verify_project.py` reported67 pages,46 bookmarks, no outside-page text, no suspiciously empty pages, three fully decoded216-frame videos with audio, and `failures: []`. The67-page contact sheet was visually inspected.
- 2026-09-07 - First packaging pass: `python docs/package_project.py` created a72.9MB complete archive with153 entries and a2.0MB printable archive with27 STLs plus schedule/manifest/notes. Both `ZipFile.testzip()` checks returned `None`, inventory revision was`C`, and no retired pod/bracket/serial-driver/old-servo-envelope path was present. A final packaging pass remains after review so the archive contains the terminal plan and any fixes.
- 2026-09-07 - Began the required two-axis code review against fixed point`205a69b`. `docs/agents/issue-tracker.md` is absent, so the committed revision C `plan.md` and user-confirmed request are the spec source; the supplied workspace instructions plus the review smell baseline are the standards source.
- 2026-09-07 - Standards review found one hard plan-record violation and three judgement calls. The hard finding was relative/prose-only milestone proof. Replaced every workstream proof with an absolute-path PowerShell command and explicit pass output. Removed the unused variable-frequency parameter from `pulse_to_duty_cycle` and extracted one channel validator used by both config and driver boundaries. Did not replace the three four-joint config arrays with a new public per-joint schema because that judgement-call change would expand the requested scope and wire format.
- 2026-09-07 - Spec review found three stale revision B remnants: E32 still bought a bus-adapter USB cable, `docs/printing.md` still counted sensors in head mass, and the package still included local ST3215 reference assets. Removed E32, assigned sensors to base mass, and excluded the legacy servo reference names/directories from packaging without deleting the operator's local untracked reference files.
- 2026-09-07 - Review-fix verification: `python -m unittest discover -s tests -v` passed38 tests in0.372s. `python docs/build_bom.py` returned `79 purchase lines, $745.07 standard + $60.80 optional DSI head; 24 standard and 3 optional printable types`. The rebuilt67-page manual and `python validation/verify_project.py` returned no clipped/empty pages and `failures: []`.
- 2026-09-07 - Review-fix packaging pass created a71.9MB complete archive with148 entries and a2.0MB printable archive with27 STLs plus three support files. Both ZIP integrity checks returned`None`, revision was`C`, and searches of archive names found no ST3215, pod, retainer, brow-bracket, serial-driver or old servo-envelope artifacts.
- 2026-09-07 - Committed review fixes as`0852aab`. Standards re-review confirmed the absolute proof commands, shared PCA channel validator and fixed50Hz conversion; it reported no remaining hard issue. Spec re-review confirmed E32 removal, base/head mass correction, legacy-reference package exclusion, five pedestal boards, four DS3218MG units and one PCA9685; it reported no remaining spec issue. The parallel array config remains intentionally unchanged because a new public config schema is outside this task.
- 2026-09-07 - Terminal package rebuild after both re-reviews again produced148 complete-project entries and27 printable STLs plus three support files. The next command reruns packaging once more so this completed status and log are present inside the archive; its ZIP result is the terminal package proof.

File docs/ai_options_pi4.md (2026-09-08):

# AI options for LUMA on Raspberry Pi 4 (8 GB)

Checked against primary sources on 8 September 2026. This is a design study, not a record of tests on assembled hardware.

## Recommendation

Keep motion control deterministic and add AI in stages:

1. Start with CPU-only voice. Use a USB microphone, local wake-word detection, streaming speech recognition, and the existing `espeak-ng` output. Map a small set of spoken intents to existing scenes. This is enough for commands such as “look at me”, “say hi”, “wink”, “stop”, and “light on”.
2. Add the **$70 Raspberry Pi AI Camera** on CSI when vision is wanted. It is the best-supported Pi 4 vision option. It performs inference in the sensor and has official Pi 4 object-detection and pose examples.
3. Add a small local language model only for conversation and intent proposals. Start with Qwen3 0.6B or 1.7B in a 4-bit GGUF file through `llama.cpp`. Do not put it in the motor-control path.
4. Buy a USB accelerator only for a measured need. Choose an OAK camera when near-field depth is required. Choose Coral only when a known Edge-TPU model and a separate legacy runtime are acceptable.

No well-supported Pi 4 plug-in currently accelerates both vision and a local language model. The official Hailo boards require Raspberry Pi 5. ASUS UGen300 is an interesting USB language-and-vision accelerator, but ASUS does not document Raspberry Pi 4 or Raspberry Pi OS support. It should be treated as an evaluation device, not a purchase recommendation.

## What the Pi 4 can do without an accelerator

| Workload | Practical software | Pi 4 use |
| --- | --- | --- |
| Object detection | Picamera2, OpenCV, and LiteRT with a quantized MobileNet-class model | Good for a proof of concept at reduced input size and a limited frame rate. Raspberry Pi maintains a current [Picamera2 LiteRT example](https://github.com/raspberrypi/picamera2/blob/main/examples/tensorflow/real_time.py). Reserve full-rate vision for a camera accelerator. |
| Pose and hand gesture | LiteRT or MediaPipe Tasks on sampled frames | Feasible, but it competes with speech and the language model for the four CPU cores. MediaPipe exposes live-stream [pose](https://ai.google.dev/edge/api/mediapipe/python/mp/tasks/vision/PoseLandmarker) and [gesture](https://ai.google.dev/edge/api/mediapipe/python/mp/tasks/vision/GestureRecognizer) tasks. Verify an ARM64 wheel on the exact Raspberry Pi OS image before selecting it. |
| Wake word | `openWakeWord`, or `sherpa-onnx` keyword spotting | Light enough to run continuously. `openWakeWord` reports that one Raspberry Pi 3 core can run 15–20 models in real time and supports Arm64 Linux noise suppression; use only one tuned wake phrase for LUMA. See the [official repository](https://github.com/dscripka/openWakeWord). |
| Speech recognition | `sherpa-onnx` streaming Zipformer; `whisper.cpp` tiny/base for utterances | `sherpa-onnx` has current Linux AArch64 packages and documents its streaming models as real-time on Pi 4. It also supplies keyword spotting, voice-activity detection, and TTS in one runtime. See its [platform list](https://github.com/k2-fsa/sherpa-onnx), [Pi 4 model guidance](https://k2-fsa.github.io/sherpa/onnx/pretrained_models/small-online-models.html), and [CPU installation](https://k2-fsa.github.io/sherpa/onnx/python/install.html). `whisper.cpp` officially supports Raspberry Pi; its tiny and base models use about 273 MB and 388 MB respectively and can be quantized. See the [`whisper.cpp` README](https://github.com/ggml-org/whisper.cpp). |
| Speech synthesis | Existing `espeak-ng`; Piper for a more natural voice | Keep `espeak-ng` as the low-load fallback. Current Piper supplies an Arm64 Raspberry Pi 4 binary and a persistent server so the model need not reload for each sentence. Piper is GPL-3.0. See the [Piper project](https://github.com/OHF-Voice/piper1-gpl) and [Pi 4 CLI notes](https://github.com/OHF-Voice/piper1-gpl/blob/main/docs/CLI.md). |
| Local language model | `llama.cpp`; Ollama for easier model management | Use a small model and a short context. `llama.cpp` supports ARM CPU inference, 2–8-bit quantization, a local API server, and grammar-constrained JSON. Qwen publishes 0.6B and 1.7B Qwen3 models under Apache 2.0 and supports `llama.cpp` and Ollama. See [`llama.cpp`](https://github.com/ggml-org/llama.cpp), [Qwen3](https://github.com/QwenLM/Qwen3), and the [Ollama Arm64 package](https://docs.ollama.com/linux). |

Engineering judgment: a 0.6B or 1.7B 4-bit model is the sensible starting range while audio and control remain live. A 4B 4-bit model may fit in 8 GB, but latency and memory pressure must be measured. A 7B model is not a practical default for simultaneous vision, speech, face rendering, and motion control. Disable Qwen “thinking” mode for short robot commands. Limit model threads and context so the controller always has CPU time.

Vosk is small, but its current official installation page still limits Python to 3.5–3.9. That conflicts with LUMA’s Python 3.11 baseline, so it is not the first choice despite official Raspberry Pi support. See the [Vosk installation page](https://alphacephei.com/vosk/install) and [model sizes](https://alphacephei.com/vosk/models).

## Add-on comparison

| Option | Performance and runtime | Pi 4 and LUMA integration | Power, heat, size, and price |
| --- | --- | --- | --- |
| **Raspberry Pi AI Camera** | Sony IMX500 runs its own image stream. Official packages include MobileNet SSD and PoseNet, with Picamera2 examples for detection, pose, classification, segmentation, and custom packaged models. Input tensors are at most 640 × 640 INT8/UINT8. Raspberry Pi does not publish a TOPS rating. See the [AI Camera documentation](https://www.raspberrypi.com/documentation/accessories/ai-camera.html). | Explicitly supported on Pi 4 over CSI. It leaves USB and the Pi CPU available. It does not accelerate audio, an LLM, or arbitrary host tensors. It can coexist electrically with either LUMA display because CSI is separate from USB and DSI. | 25 × 24 × 11.9 mm, 6 g, 0–50 °C, supplied cable 200 mm, official list price **$70**. See the [product brief](https://datasheets.raspberrypi.com/camera/ai-camera-product-brief.pdf) and [product page](https://www.raspberrypi.com/products/ai-camera/). |
| **Luxonis OAK-D Short Range** | RVC2 provides 4 TOPS total and 1.4 TOPS for neural inference. It runs converted models, cameras, tracking, encoding, and stereo processing on the device through current DepthAI software. Its stated ideal depth range is 30 cm–1 m, which fits a desk companion. See the [RVC2 specification](https://docs.luxonis.com/hardware/platform/rvc/rvc2) and [DepthAI neural-network support](https://docs.luxonis.com/software-v3/depthai/depthai-components/nodes/neural_network). | Works as a USB 2/3 peripheral; Luxonis provides Raspberry Pi deployment instructions and AArch64 wheels. It brings its own cameras. Mount it on the fixed pedestal or desk, not the moving head. It is the best choice when real depth is more important than minimum cost. | 56 × 36 × 25.5 mm and 72 g. RVC2 cameras use about 2.5–3 W for streaming, plus up to 1 W for AI, 0.5 W for stereo, and 0.5 W for encoding. Current official price is **$229**. See the [OAK-D Short Range shop page](https://shop.luxonis.com/products/oak-d-sr) and [USB power guidance](https://docs.luxonis.com/hardware/platform/deploy/usb-deployment-guide/). Use a powered USB 3 hub. |
| **Coral USB Accelerator** | 4 TOPS INT8 at 2 W, over USB 3. It accepts only fully 8-bit TensorFlow Lite models compiled for Edge TPU; unsupported operations fall back to the host CPU. See the [datasheet](https://coral.ai/static/files/Coral-USB-Accelerator-datasheet.pdf) and [model rules](https://coral.ai/docs/edgetpu/models-intro/). | Google explicitly lists Pi 4. However, its official guide requires Python 3.6–3.9, while LUMA requires 3.11+. The [PyCoral](https://github.com/google-coral/pycoral) and [libedgetpu](https://github.com/google-coral/libedgetpu) repositories were archived in 2025. Use a separate Python 3.9 process or the C++ API and freeze the image. This is a fixed-function vision option, not an LLM accelerator. | 65 × 30 × 8 mm. It needs at least 500 mA at 5 V and can peak near 900 mA at maximum clock. Maximum-clock mode consumes more power and can make the metal case burn-hot; use reduced clock and ventilation. Google no longer publishes a current first-party price. See the [official setup guide](https://coral.ai/docs/accelerator/get-started/). |
| **ReSpeaker XVF3800 USB 4-Mic Array** | This is an audio front-end, not a general neural accelerator. Its XMOS processor performs acoustic echo cancellation, gain control, voice-activity detection, direction finding, beamforming, noise suppression, and dereverberation before audio reaches the Pi. | Official USB firmware is plug-and-play on Raspberry Pi OS. It improves far-field speech while reducing Pi audio work. Prefer the enclosed USB model and evaluate using its audio output in place of the current USB speaker, so echo cancellation has a playback reference and one USB device can replace two. | Four microphones, stated pickup to 5 m. Current enclosed-model price is **$62.99**. See the [setup guide](https://wiki.seeedstudio.com/respeaker_xvf3800_introduction/) and [official shop page](https://www.seeedstudio.com/ReSpeaker-XVF3800-USB-4-Mic-Array-With-Case-p-6490.html). |
| **ASUS UGen300 USB** | Hailo-10H, 40 TOPS INT4 or 20 TOPS INT8, 8 GB LPDDR4, with vendor claims for vision, LLM, VLM, and Whisper workloads. Hailo models use HailoRT and compiled HEF files. | ASUS lists ARM Linux and SBC use, but does not list Pi 4 or Raspberry Pi OS. Its USB 3.1 Gen 2 link is 10 Gbit/s; Pi 4 USB 3 is limited to 5 Gbit/s. Driver behavior and performance at the reduced link are unverified. Obtain vendor confirmation or a returnable evaluation unit before purchase. | 105 × 50 × 18 mm, 150 g, 2.5 W typical. No first-party US price was found. See the [ASUS announcement](https://press.asus.com/news/press-releases/asus-ugen300-usb-ai-accelerator-generative-ai-edge/), [technical specification](https://www.asus.com/ca-en/motherboards-components/ai-accelerator/ugen/ugen300-usb-8g/techspec/), and [official utility](https://github.com/Asus-UGen-Series/Ugen-Utility). |

## Options that do not fit this Pi 4

- Raspberry Pi AI Kit, AI HAT+, and AI HAT+ 2 require the exposed PCIe connector on Raspberry Pi 5. A standard Pi 4 Model B does not expose PCIe, so an M.2 HAT, raw Hailo module, or USB NVMe enclosure cannot make these products work. The current HATs provide 13 or 26 TOPS for vision; AI HAT+ 2 provides 40 TOPS and 8 GB accelerator RAM for LLMs, but it is a **Pi 5 platform change**, not a Pi 4 add-on. See the [AI HAT hardware requirements](https://www.raspberrypi.com/documentation/accessories/ai-hat-plus.html), [AI HAT+ product](https://www.raspberrypi.com/products/ai-hat/), and [AI HAT+ 2 product](https://www.raspberrypi.com/products/ai-hat-plus-2/).
- Do not buy an Intel Neural Compute Stick 2 for a new build. Intel ended shipments in 2022, technical support in 2023, and warranty support in 2024. NCS2 is held on OpenVINO 2022.3 LTS. See Intel’s [end-of-life notice](https://www.intel.com/content/www/us/en/support/articles/000090446/boards-and-kits/neural-compute-sticks.html) and [OpenVINO support notice](https://www.intel.com/content/www/us/en/support/articles/000093181/boards-and-kits.html).

## Interface, power, and physical limits

The Pi 4 has two USB 3 ports and two USB 2 ports, with only **1.2 A total** available to all USB peripherals. LUMA already assigns USB to the ESP32-S3 face and speaker. A microphone plus a Coral or OAK device can fill all four physical ports and exceed the power budget. Use a quality externally powered USB 3 hub for any USB accelerator or OAK camera. A powered hub adds power and ports; it does not add Pi host bandwidth. See the [Raspberry Pi USB limits](https://www.raspberrypi.com/documentation/computers/raspberry-pi.html#universal-serial-bus-usb) and LUMA’s existing [electrical architecture](../electronics/architecture.md).

The following combinations need explicit treatment:

- AI Camera plus the standard USB face and USB audio is electrically compatible. The camera uses CSI.
- AI Camera plus the optional DSI face is also electrically compatible. CSI and DSI are separate. The mechanical cable route is not solved.
- OAK plus Coral is technically possible through separate USB ports, but the accelerators do not pool memory or compute. They run separate model formats and runtimes, consume the same limited USB power and bandwidth, and are redundant for this project.
- No Pi 5 AI HAT, AI Kit, or M.2 accelerator can be combined with the standard Pi 4 Model B.
- The supplied AI Camera cable is 200 mm. LUMA has no camera mount or moving CSI harness. A camera on the head would require new printed parts, a longer flex cable, bend and strain-relief validation through every joint, and a new head-mass and torque check. A fixed pedestal camera is the low-risk first build.
- Place Coral, a powered hub, or an ASUS evaluation unit in a ventilated fixed location. Do not add their mass or stiff cables to the wrist. The OAK-D Short Range is also best fixed to the base or desk.

Sustained CPU inference needs active airflow. Raspberry Pi states that Pi 4 progressively throttles its Arm cores from 80–85 °C and recommends a fan for best sustained performance. LUMA already calls for a heatsink and ventilation; add a fan only after checking GPIO conflicts and measuring the closed pedestal. See the [official thermal guidance](https://www.raspberrypi.com/documentation/computers/raspberry-pi.html#frequency-management-and-thermal-control).

## Safe control boundary

AI output must be advice to the existing controller, never a servo command:

```text
microphone -> wake word -> speech text ----+
                                             +-> intent proposal -> allowlist -> LUMA controller
camera ----> object/pose/gesture events ----+                         |
                                                                      +-> existing arming, limits, faults, PCA9685
```

The allowlist should accept a few high-level intents with a confidence threshold, freshness limit, rate limit, and timeout. It should reject unknown text and stale perception. The LLM must not write `config.json`, set `calibrated=true`, arm the mechanism, clear a fault, select pulse widths, or bypass the range checks. Loss of the AI process must leave the deterministic controller operating or holding safely.

Keep the independent motor-power stop. LUMA’s five VL53L1X sectors and any camera inference are not safety-rated and do not cover every pinch point. The servos have no readable position, current, or temperature. A software fault can leave the PCA9685 at its last pulse widths, so unexpected motion still requires the physical motor stop. These limits and the first-motion procedure are already recorded in [electronics/architecture.md](../electronics/architecture.md) and [software/README.md](../software/README.md).

## Proof before the next stage

For each stage, record on the actual 8 GB Pi 4:

- wake false-accept and false-reject counts in the intended room;
- median and 95th-percentile speech and intent latency;
- camera inference rate, end-to-end event latency, and false detections;
- CPU and memory use while face, audio, sensors, and one scene run together;
- `vcgencmd measure_temp` and `vcgencmd get_throttled` before and after a 30-minute sustained test;
- USB disconnects, undervoltage reports, and hub behavior under peak load;
- behavior when the microphone, camera, model process, display, sensor, or PCA9685 is unplugged;
- confirmation that no AI event can arm, clear a latched fault, or generate raw motor output.

Advance only when the current stage meets a written latency target without throttling, undervoltage, dropped safety polling, or unexpected motion.

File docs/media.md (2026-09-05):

# Finished design and promotional films

The promotional films show the LUMA digital prototype built from the supplied CAD geometry. The lighting, camera exposure, screen graphics and sound are presentation choices; the films do not establish the physical lamp's brightness, motor sound or production finish.

Finished LUMA digital prototype, rendered from the project geometry.

## The three films

| Film | Included file | Action |
| --- | --- | --- |
| The wink | `media/videos/01_wink.mp4` | A brief one-eye wink with a coordinated head gesture and colored halo. |
| Hi, there | `media/videos/02_hi.mp4` | A friendly face greeting, arm gesture and an audible “Hi!” |
| Happy to see you | `media/videos/03_happy.mp4` | Cheerful eyes and a small happy movement, with warm halo color. |

Open `START_HERE.html` in a browser after extracting the archive to play all three clips. The videos are also individual files for editing or presentation use. The project includes editable animation sources under `media/sources/`.

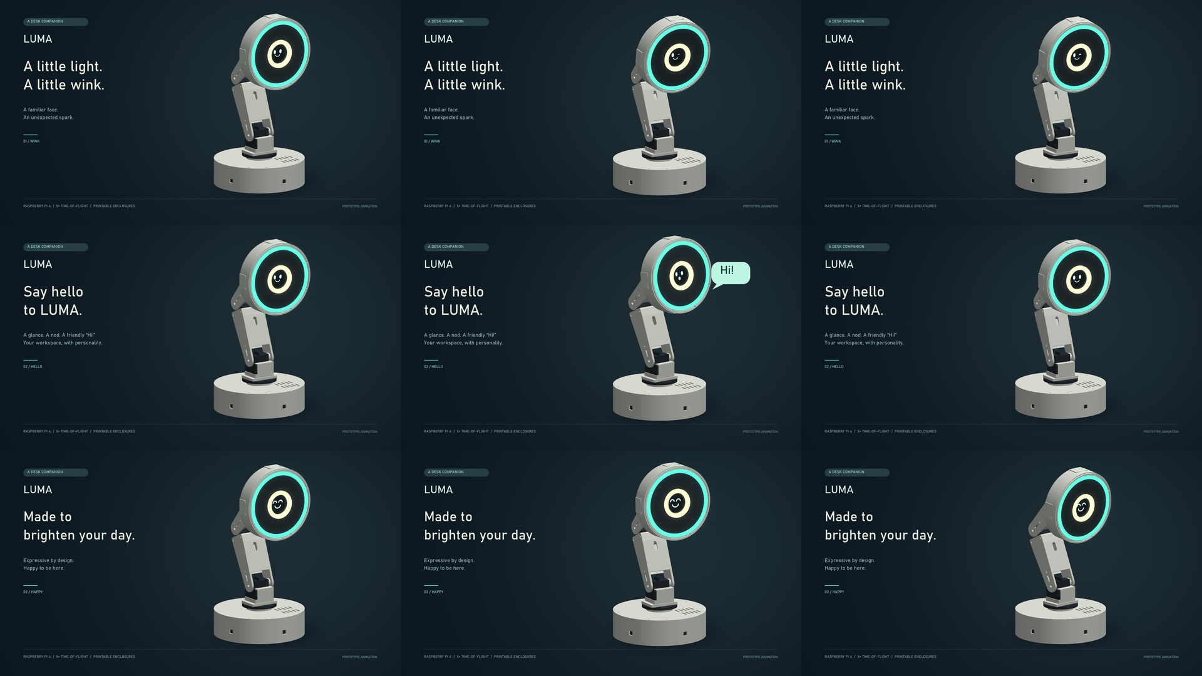
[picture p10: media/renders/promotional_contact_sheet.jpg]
Frames from the three included promotional animations.


## Assembly visualization

Exploded view of the prototype. Explode distances expose components and do not prescribe insertion travel.

Optional 4-inch DSI head, rendered from with the same enclosed arm and base.

The engineering sheets at the back of the manual are the dimensional references. The rendered images explain appearance and assembly relationships; use the numbered assembly sequence for fasteners, wiring and the optical stack.

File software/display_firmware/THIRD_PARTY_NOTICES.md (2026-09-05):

The graphics library is Arduino_GFX v1.6.5 by Moon On Our Nation and its contributors, obtained through PlatformIO under its own license:
https://github.com/moononournation/Arduino_GFX/tree/v1.6.5

`src/panel_init.h` contains hardware register data converted to the Arduino_GFX operation format from the Waveshare ESP32-S3-Touch-LCD-1.85 reference demo (archive published2025-04-18). Default table original copyright2023 Espressif Systems (Shanghai) CO LTD, Apache-2.0. The board vendor's revised table is in `Arduino/examples/LVGL_Arduino/Display_ST77916.cpp`; the original default is in `esp_lcd_st77916.c`. Command values, data byte order and waits were retained; RGB565 format is explicitly set at the end.

Source archive:
https://files.waveshare.com/wiki/ESP32-S3-Touch-LCD-1.85/ESP32-S3-Touch-LCD-1.85-Demo.zip

Apache2.0 license text:
https://www.apache.org/licenses/LICENSE-2.0.txt

No audio recordings, vendor speech models, or example applications are redistributed in the project deliverable.

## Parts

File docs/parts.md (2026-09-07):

# Parts and purchasing

Planning allowance for the standard build below: **US $745.07** before shipping and tax. The optional 4-inch DSI head adds **US $60.80** of purchased parts and removes the 1.85-inch display, the inner RGBW ring and their fasteners (about US $68.35). Figures are budgeting allowances, not checked-out prices. Filament and any workshop tools are included only where explicitly listed. Reuse of existing supplies can change the total substantially.

Order the exact display and voltage variant specified. Generic fasteners, connector harnesses, relay contacts and wire must meet the listed dimensions and electrical ratings. Buy the servo horns and their screws with the servos; verify their actual thread and engagement before ordering extras.

## Controller, sensing, lights and power

| Ref / qty | Item | Required specification | Budget / each |
| --- | --- | --- | --- |
| E01 / 1 | [Raspberry Pi Raspberry Pi 4 Model B 4GB](https://www.raspberrypi.com/products/raspberry-pi-4-model-b/) | Master controller. 40-pin GPIO and four USB ports | $60.00 |
| E02 / 1 | [Raspberry Pi 15W USB-C Power Supply](https://www.raspberrypi.com/products/type-c-power-supply/) | Separate Pi supply. 5.1V 3A USB-C | $12.00 |
| E03 / 1 | Reputable flash vendor 32GB or larger microSD A1 | Operating system card. High endurance preferred | $12.00 |
| E04 / 1 | [Waveshare ESP32-S3-Touch-LCD-1.85 SKU28514](https://docs.waveshare.com/ESP32-S3-Touch-LCD-1.85) | Central face display. 55x55mm;360x360 ST77916 QSPI;USB-C;no B/C suffix | $35.00 |
| E05 / 5 | [Adafruit 3967 VL53L1X STEMMA QT](https://www.adafruit.com/product/3967) | Five interaction ranging sensors. 25.5x17.5x4.6mm;I2C0x29 | $14.95 |
| E06 / 1 | [Adafruit 5626 PCA9548 STEMMA QT](https://www.adafruit.com/product/5626) | Mux for five same-address sensors. TCA9548A-compatible;40.6x20.2x4.8mm;0x70 | $6.95 |
| E07 / 5 | [Adafruit STEMMA QT JST-SH4 cable](https://www.adafruit.com/category/619) | One separate cable per sensor. Length selected to assembled routing;100-300mm nominal | $2.00 |
| E08 / 1 | [Adafruit STEMMA QT to female header cable](https://www.adafruit.com/category/619) | Pi to mux upstream connector. 3.3V logic only | $2.00 |
| E09 / 4 | [Adafruit 1768 quarter NeoPixel60 ring](https://www.adafruit.com/product/1768) | Outer RGB emotion halo. 15RGB per quadrant;four form OD157.5mm ID144.8mm ring | $9.95 |
| E10 / 1 | [Adafruit 2862 NeoPixel24 RGBW natural white](https://www.adafruit.com/product/2862) | Inner white lamp ring. 24RGBW;OD65.5mm;only W channel used;4500K nominal | $24.95 |
| E11 / 1 | [Adafruit 1787 74AHCT125 DIP14](https://www.adafruit.com/product/1787) | Two data level shifters. 5V VCC;3.3V logic accepted;AHCT required | $1.50 |
| E12 / 2 | Generic 330ohm 0.25W resistor | LED input series resistors. One per independent data line | $0.10 |
| E13 / 2 | Generic 1000uF 10V electrolytic | LED ring supply reservoir. Observe polarity;one each ring | $1.00 |
| E14 / 1 | Generic 100nF ceramic | 74AHCT125 decoupling. Across DIP14 and DIP7 at socket | $0.10 |
| E15 / 1 | [Pololu D24V50F5 item2851](https://www.pololu.com/product/2851) | LED5V buck converter. 5V5A typical thermal-limited;17.8x20.3x8.8mm | $32.95 |
| E16 / 4 | [Miuzei DS3218MG 20kg 270-degree](https://images-na.ssl-images-amazon.com/images/I/81Lbgu%2BnG6L.pdf) | Four inventory joint servos. 4.8-6.8V; PWM500-2500us;1500us neutral;50-330Hz;2.2A stall and21.5kg-cm at6.8V;40x20x40.5mm | $0.00 |
| E17 / 1 | [Generic PCA9685 16-channel PWM board](https://learn.adafruit.com/16-channel-pwm-servo-driver) | Operator-selected four-servo controller. I2C address0x40;50Hz;channels0-3;3.3V logic VCC;servo V+ supplied separately | $0.00 |
| E18 / 1 | [Mean Well GST220A12-R7B](https://www.meanwell.com/Upload/PDF/GST220A/GST220A-SPEC.PDF) | External enclosed motor/LED supply. 12V15A model;R7B powerDIN;keep outside printed enclosure | $95.00 |
| E19 / 1 | Generic Matching R7B powerDIN harness | DC supply breakout. Correct polarity;all specified parallel contacts;15A aggregate rated | $15.00 |
| E20 / 1 | Generic IEC C13 mains cord | External supply cord. Local approved cord;earth conductor intact | $7.00 |
| E21 / 1 | Generic Latching mushroom stop two NC contacts | Motor stop plus isolated Pi sense. NC1 interrupts12V relay coil;NC2 connects BCM27 to GND | $15.00 |
| E22 / 1 | Generic 12VDC coil relay with30A DC NO contact and socket | Hardware motor supply disconnect. Coil<=200mA;NO contacts>=15A at12VDC;socket16AWG | $12.00 |
| E23 / 1 | Generic 1N4007 diode | Relay coil flyback. Stripe/cathode to coil positive | $0.10 |
| E24 / 1 | Generic 15A DC fuse and holder | Main12V input branch. Holder and connector rated>=15A | $3.00 |
| E25 / 4 | Generic 3A time-delay DC fuse and holder | Individual6V servo feeds. 18AWG star feeds;one fuse per DS3218 | $3.00 |
| E26 / 1 | Generic 2A DC fuse and holder | Buck12V input branch. LED firmware capped20percent | $3.00 |
| E27 / 1 | Generic 7.5A time-delay DC fuse and holder | Servo regulator12V input branch. Between motor relay output and6V regulator VIN;16AWG | $3.00 |
| E28 / 1 | Generic 0.5A DC fuse and holder | Relay coil branch. NC1 switches coil only | $3.00 |
| E29 / 1 | Generic 3A DC fuse and holder | 5V LED output branch. ProtectsLED18-22AWG harness | $3.00 |
| E30 / 1 | [Adafruit 3369 mini USB speaker](https://www.adafruit.com/product/3369) | Spoken Hi. USB audio;84x43x32mm;73.6g;keep volume modest | $12.50 |
| E31 / 1 | Generic USB-A to right-angle USB-C data cable | Pi to display. Flexible cable;strain relief;15mm rear plug envelope assumed | $7.00 |
| E33 / 1 | Generic 16AWG /18AWG silicone wire and rated distribution terminals | Power harness. 16AWG trunk;18AWG motor branches;22AWGLED branches | $20.00 |
| E34 / 1 | Generic Small perfboard and DIP14 socket | Level shifter assembly. Insulate underside;strain relief all wires | $5.00 |
| E35 / 1 | Generic Pi4 heatsink and ventilation hardware | Thermal management. Check CPU temperature after assembled operation | $7.00 |
| E36 / 1 | Generic 10kohm resistor | External E-stop sense pullup. BCM27 to3.3V;open NC2 means asserted | $0.10 |
| E37 / 1 | [Pololu D42V110F6 item5673](https://www.pololu.com/product/5673) | Servo rail step-down regulator. 6V output;11A nominal;6-60V input;31.8x43.2x9mm;four2.2mm mounting holes | $59.95 |
| E38 / 1 | [Generic 2200uF 10V low-ESR electrolytic](https://learn.adafruit.com/16-channel-pwm-servo-driver/hooking-it-up) | Servo rail bulk capacitor. Across6V star after regulator;observe polarity;voltage rating at least10V | $3.00 |

## Mechanical hardware and consumables

| Ref / qty | Item | Required specification | Budget / each |
| --- | --- | --- | --- |
| M01 / 1 | [Local metal supplier Custom ballast disc](https://www.onlinemetals.com/) | Steel ballast plate. Mild steel diameter180 thickness6 mm; 4 holes diameter4.4 at XY(+/-45,+/-35); 4 holes diameter3.4 at XY(+/-26,-36/-8); deburr; approx1.19kg | $25.00 |
| M02 / 1 | [Generic 6808-2RS](https://www.skf.com/group/products/rolling-bearings/ball-bearings/deep-groove-ball-bearings) | Yaw support bearing. 40mm bore x52mm OD x7mm width; sealed deep groove | $12.00 |
| M03 / 4 | Generic M4x25 | Base and tray bolts. M4 x25 socket head; steel plate6 + floor3 + spacer5 + tray3 | $0.25 |
| M04 / 4 | Generic M4x5 spacer | Tray standoffs. Metal spacer5mm length; 4.3mm bore; OD8 minimum | $0.40 |
| M05 / 4 | [Generic M4 nut]( ) | M4 lock nuts. ISO metric nyloc | $0.12 |
| M06 / 8 | [Generic M4 washer]( ) | M4 load spreading washers. OD12 minimum | $0.06 |
| M07 / 4 | Generic M3x16 | Yaw cradle through bolts. Through printed cradle3 steel6 and base3; nuts below base; tray has7mm head access | $0.16 |
| M08 / 2 | Generic M3x50 | Yaw rear body clamp bolts. Through bottom3 + body40.5 + keeper2.6; do not overtighten case | $0.30 |
| M09 / 2 | [Generic M3x60]( ) | Shoulder clamp bolts. Clamp through the52mm tower width and keeper plus nuts | $0.40 |
| M10 / 4 | [Generic M3x16]( ) | Shoulder foot bolts. 6mm tower foot plus6mm platform plus nuts | $0.16 |
| M11 / 6 | Generic M3x70 | Arm link through bolts. 5+52+5mm stack plus nut;3 per link at X35 and around each servo block | $0.45 |
| M12 / 8 | [Generic M3x12 nominal with matching nuts](https://images-na.ssl-images-amazon.com/images/I/81Lbgu%2BnG6L.pdf) | DS3218 straight-horn attachment sets. Two per joint through adjustable printed slots; actual supplied horn hole size and thread are not documented | $0.25 |
| M14 / 6 | [Generic M3x12]( ) | Base lid screws. Into2.8mm plastic-thread-forming printed pilots | $0.15 |
| M15 / 4 | Generic M3x12 | Head yoke screws. 6mm fork mounting face +3mm shell floor; nuts on inside | $0.15 |
| M16 / 8 | Generic M3x10 | Outer bezel screws. 4mm bezel +1mm shim;2.8mm plastic-thread-forming pilot | $0.15 |
| M17 / 4 | Generic M3x12 | Central face screws. 4mm plate +1mm shim;2.8mm plastic-thread-forming pilot | $0.15 |
| M18 / 4 | Generic M3x10 | White ring carrier screws. 2mm carrier on dedicated radius45 bosses at z32.5 | $0.15 |
| M19 / 4 | Generic M3x25 | LCD cradle and retaining plate screws. 3mm retainer +15mm cradle; thread into head pillar at z14 | $0.20 |
| M20 / 12 | Generic M3x1 shim | Precision axial shims. M3 bore; thickness1mm;12 under face and bezel | $0.12 |
| M21 / 20 | Generic M2.5x6 | Pedestal sensor board screws. Four per Adafruit3967 board into2.1mm blind pilots;20.32x12.70mm pattern | $0.12 |
| M24 / 30 | [Generic M3 nut]( ) | General M3 nuts. Include spare quantities for clamps horn interfaces and platform | $0.10 |
| M25 / 50 | [Generic M3 washer]( ) | General M3 flat washers. Nominal0.5mm; not replacement for1mm axial shims | $0.05 |
| M26 / 4 | Generic M2.5x6 | Raspberry Pi fasteners. Pi4 four mounting holes; printed standoffs may be tappedM2.5 | $0.12 |
| M27 / 4 | Generic Rubber feet | Adhesive anti slip feet. 20mm diameter x5mm high minimum; place radius90 | $0.40 |
| M28 / 1 | Generic Translucent PETG | Frosted optical printing filament. Natural/translucent; approximately60g including trials; solid1.2mm optical skin | $20.00 |
| M29 / 1 | Generic PETG | Structural filament. Approx1kg roll; actual slicer mass varies;6 walls on the arm link halves | $22.00 |
| M30 / 1 | Generic Neutral cure silicone | Small adhesive tube. 3 small removable dots for inner diffuser; electronics compatible | $6.00 |
| M31 / 1 | Generic Thin PCB foam | Closed cell foam tape. 0.5 and1mm thickness; LCD edge preload only | $4.00 |
| M32 / 1 | [Generic LED retaining tape]( ) | Electronics compatible thin adhesive strips. Attach LED ring PCB on support posts without covering LED optics | $3.00 |
| M33 / 1 | Generic Desk clamp | Optional commercial padded desk clamp. Use only if assembly reach/mass exceeds validated stable envelope; not a printed load bearing clamp | $12.00 |
| M34 / 12 | [Generic M2.5x12]( ) | Optional harness clip screws. For6 printed cable saddles; use selftapped pilots or cableties | $0.12 |
| M35 / 3 | Generic 625-2RS | Pitch-joint idler bearings. 5mm bore x16mm OD x5mm width; sealed | $3.00 |
| M36 / 3 | Generic M5x16 shoulder bolt or precision-shank bolt | Pitch-joint idler axles. Smooth5mm shank across each625 inner race; one shoulder elbow wrist | $0.80 |
| M37 / 3 | Generic M5 nyloc nut | Pitch-joint captive idler nuts. ISO metric; one in each printed hex trap | $0.20 |
| M38 / 6 | Generic M5 washer | Idler bearing thrust washers. One each side of every625 inner race; thin hardened steel | $0.12 |

## Optional 4-inch DSI head (not in the standard total)

Buy these only for the optional head described in the mechanical chapter. With this head, do not buy E04 (1.85-inch display), E10 (24-pixel RGBW ring), E31 (display USB cable), M18 (white ring carrier screws) or M19 (LCD cradle screws).

| Ref / qty | Item | Required specification | Budget / each |
| --- | --- | --- | --- |
| D01 / 1 | [Waveshare 4inch DSI LCD (C)](https://www.waveshare.com/4inch-dsi-lcd-c.htm) | Optional head display. Round720x720 IPS DSI;126mm outline;101.52mm active;6mm case;four M4 rear bosses on75x75;includes two50mm 15-pin FPC | $45.00 |
| D02 / 1 | Generic 15-pin 1.0mm pitch FFC type A 800mm | Pi DSI to optional head. Same-side contacts;0.3mm thick;800mm nominal from Pi DSI connector through both arm cable ports;bench-verify signal integrity before closing the arm | $8.00 |
| D03 / 1 | Generic 2-conductor 22AWG silicone lead with2.0mm pitch 4-pin plug | Optional head5V feed. Pi header5V/GND to LCD HP2.0 4-pin;SDA/SCL contacts left empty;800mm | $4.00 |
| D10 / 4 | Generic M4x8 | Optional LCD carrier to display screws. Through5mm carrier pad into the4mm deep M4 case bosses; longer screws bottom out | $0.15 |
| D11 / 4 | Generic M3x8 | Optional carrier to shell screws. Into2.8mm printed pilots at(+/-55,+/-38) top20.5 | $0.15 |
| D12 / 4 | Generic M3x12 | Optional face ring screws. 4mm ring +1mm shim;2.8mm pilots at radius67.8 | $0.15 |
| D14 / 1 | Generic Thin closed cell foam tape | Optional LCD rim preload. 0.5mm between the display case rim and the face ring; also under the carrier pads if the boss ends are not coplanar | $2.00 |

## Printable part schedule

24 unique STL files; 31 printed pieces for the standard build, including the fit coupon and optional cable clips. Quantities control the print run. The drawing index uses the same part order.

| Drawing / qty | STL identifier | Material / print orientation |
| --- | --- | --- |
| P01 / 1 | `base_tub` | PETG; floor down |
| P02 / 1 | `base_lid` | PETG; flat annulus down |
| P03 / 1 | `electronics_tray` | PETG; plate down |
| P04 / 1 | `yaw_mount` | PETG; base down |
| P05 / 1 | `yaw_cap` | PETG; flat down |
| P06 / 1 | `turntable` | PETG; neck down |
| P07 / 1 | `shoulder_tower` | PETG; foot down |
| P08 / 1 | `shoulder_cap` | PETG; flat down |
| P09 / 1 | `upper_arm_left` | PETG; plate down |
| P10 / 1 | `upper_arm_right` | PETG; plate down |
| P11 / 1 | `forearm_left` | PETG; plate down |
| P12 / 1 | `forearm_right` | PETG; plate down |
| P13 / 3 | `horn_spacer` | PETG; flat down |
| P14 / 1 | `head_yoke` | PETG; rear mounting plate on bed; rotate180X |
| P15 / 1 | `head_shell` | PETG; rear disc down |
| P16 / 1 | `outer_bezel` | PETG; front lip down |
| P17 / 1 | `face_center` | black PETG; flat front down |
| P18 / 1 | `white_carrier` | PETG; flat down |
| P19 / 1 | `lcd_cradle` | PETG; flat base down |
| P20 / 1 | `lcd_retainer` | black PETG; flat down |
| P21 / 1 | `outer_diffuser` | natural/translucent PETG; smooth optical face on bed |
| P22 / 1 | `inner_diffuser` | natural/translucent PETG; smooth optical face on bed |
| P23 / 6 | `cable_clip` | PETG; flat down |
| P24 / 1 | `fit_coupon` | PETG; flat down |

The optional 4-inch DSI head prints 3 additional files (3 pieces) and omits `head_shell`, `face_center`, `white_carrier`, `inner_diffuser`, `lcd_cradle`, `lcd_retainer` from the list above.

| Drawing / qty | STL identifier | Material / print orientation |
| --- | --- | --- |
| P25 / 1 | `head_shell_dsi` | PETG; rear disc down |
| P26 / 1 | `lcd4_carrier` | PETG; flat down |
| P27 / 1 | `face_ring_dsi` | black PETG; flat front down |

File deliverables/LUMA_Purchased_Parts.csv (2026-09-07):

ref | quantity | manufacturer | model | description | critical_spec | verification | source | budget_usd_each
E01 | 1 | Raspberry Pi | Raspberry Pi 4 Model B 4GB | Master controller | 40-pin GPIO and four USB ports | Vendor documented | https://www.raspberrypi.com/products/raspberry-pi-4-model-b/ | 60
E02 | 1 | Raspberry Pi | 15W USB-C Power Supply | Separate Pi supply | 5.1V 3A USB-C | Vendor documented | https://www.raspberrypi.com/products/type-c-power-supply/ | 12
E03 | 1 | Reputable flash vendor | 32GB or larger microSD A1 | Operating system card | High endurance preferred | Specification selection |  | 12
E04 | 1 | Waveshare | ESP32-S3-Touch-LCD-1.85 SKU28514 | Central face display | 55x55mm;360x360 ST77916 QSPI;USB-C;no B/C suffix | Vendor documented | https://docs.waveshare.com/ESP32-S3-Touch-LCD-1.85 | 35
E05 | 5 | Adafruit | 3967 VL53L1X STEMMA QT | Five interaction ranging sensors | 25.5x17.5x4.6mm;I2C0x29 | Vendor documented | https://www.adafruit.com/product/3967 | 14.95
E06 | 1 | Adafruit | 5626 PCA9548 STEMMA QT | Mux for five same-address sensors | TCA9548A-compatible;40.6x20.2x4.8mm;0x70 | Vendor documented | https://www.adafruit.com/product/5626 | 6.95
E07 | 5 | Adafruit | STEMMA QT JST-SH4 cable | One separate cable per sensor | Length selected to assembled routing;100-300mm nominal | Measure route before buying | https://www.adafruit.com/category/619 | 2
E08 | 1 | Adafruit | STEMMA QT to female header cable | Pi to mux upstream connector | 3.3V logic only | Specification selection | https://www.adafruit.com/category/619 | 2
E09 | 4 | Adafruit | 1768 quarter NeoPixel60 ring | Outer RGB emotion halo | 15RGB per quadrant;four form OD157.5mm ID144.8mm ring | Vendor documented | https://www.adafruit.com/product/1768 | 9.95
E10 | 1 | Adafruit | 2862 NeoPixel24 RGBW natural white | Inner white lamp ring | 24RGBW;OD65.5mm;only W channel used;4500K nominal | Vendor documented | https://www.adafruit.com/product/2862 | 24.95
E11 | 1 | Adafruit | 1787 74AHCT125 DIP14 | Two data level shifters | 5V VCC;3.3V logic accepted;AHCT required | Vendor documented | https://www.adafruit.com/product/1787 | 1.50
E12 | 2 | Generic | 330ohm 0.25W resistor | LED input series resistors | One per independent data line | Design choice |  | 0.10
E13 | 2 | Generic | 1000uF 10V electrolytic | LED ring supply reservoir | Observe polarity;one each ring | Design choice |  | 1
E14 | 1 | Generic | 100nF ceramic | 74AHCT125 decoupling | Across DIP14 and DIP7 at socket | Design choice |  | 0.10
E15 | 1 | Pololu | D24V50F5 item2851 | LED5V buck converter | 5V5A typical thermal-limited;17.8x20.3x8.8mm | Vendor documented | https://www.pololu.com/product/2851 | 32.95
E16 | 4 | Miuzei | DS3218MG 20kg 270-degree | Four inventory joint servos | 4.8-6.8V; PWM500-2500us;1500us neutral;50-330Hz;2.2A stall and21.5kg-cm at6.8V;40x20x40.5mm | Vendor datasheet; operator has8 | https://images-na.ssl-images-amazon.com/images/I/81Lbgu%2BnG6L.pdf | 0
E17 | 1 | Generic | PCA9685 16-channel PWM board | Operator-selected four-servo controller | I2C address0x40;50Hz;channels0-3;3.3V logic VCC;servo V+ supplied separately | Controller selected by operator; measure exact board before fastening | https://learn.adafruit.com/16-channel-pwm-servo-driver | 0
E18 | 1 | Mean Well | GST220A12-R7B | External enclosed motor/LED supply | 12V15A model;R7B powerDIN;keep outside printed enclosure | Vendor documented | https://www.meanwell.com/Upload/PDF/GST220A/GST220A-SPEC.PDF | 95
E19 | 1 | Generic | Matching R7B powerDIN harness | DC supply breakout | Correct polarity;all specified parallel contacts;15A aggregate rated | Must match selected supply connector drawing |  | 15
E20 | 1 | Generic | IEC C13 mains cord | External supply cord | Local approved cord;earth conductor intact | Specification selection |  | 7
E21 | 1 | Generic | Latching mushroom stop two NC contacts | Motor stop plus isolated Pi sense | NC1 interrupts12V relay coil;NC2 connects BCM27 to GND | Specify contact blocks before purchase |  | 15
E22 | 1 | Generic | 12VDC coil relay with30A DC NO contact and socket | Hardware motor supply disconnect | Coil<=200mA;NO contacts>=15A at12VDC;socket16AWG | Specify actual DC rating before purchase |  | 12
E23 | 1 | Generic | 1N4007 diode | Relay coil flyback | Stripe/cathode to coil positive | Design choice |  | 0.10
E24 | 1 | Generic | 15A DC fuse and holder | Main12V input branch | Holder and connector rated>=15A | Design choice |  | 3
E25 | 4 | Generic | 3A time-delay DC fuse and holder | Individual6V servo feeds | 18AWG star feeds;one fuse per DS3218 | Design choice |  | 3
E26 | 1 | Generic | 2A DC fuse and holder | Buck12V input branch | LED firmware capped20percent | Design choice |  | 3
E27 | 1 | Generic | 7.5A time-delay DC fuse and holder | Servo regulator12V input branch | Between motor relay output and6V regulator VIN;16AWG | Design choice |  | 3
E28 | 1 | Generic | 0.5A DC fuse and holder | Relay coil branch | NC1 switches coil only | Design choice |  | 3
E29 | 1 | Generic | 3A DC fuse and holder | 5V LED output branch | ProtectsLED18-22AWG harness | Design choice |  | 3
E30 | 1 | Adafruit | 3369 mini USB speaker | Spoken Hi | USB audio;84x43x32mm;73.6g;keep volume modest | Vendor documented | https://www.adafruit.com/product/3369 | 12.50
E31 | 1 | Generic | USB-A to right-angle USB-C data cable | Pi to display | Flexible cable;strain relief;15mm rear plug envelope assumed | Measure selected cable |  | 7
E33 | 1 | Generic | 16AWG /18AWG silicone wire and rated distribution terminals | Power harness | 16AWG trunk;18AWG motor branches;22AWGLED branches | Lengths from routing |  | 20
E34 | 1 | Generic | Small perfboard and DIP14 socket | Level shifter assembly | Insulate underside;strain relief all wires | Design choice |  | 5
E35 | 1 | Generic | Pi4 heatsink and ventilation hardware | Thermal management | Check CPU temperature after assembled operation | Specification selection |  | 7
E36 | 1 | Generic | 10kohm resistor | External E-stop sense pullup | BCM27 to3.3V;open NC2 means asserted | Design choice |  | 0.10
E37 | 1 | Pololu | D42V110F6 item5673 | Servo rail step-down regulator | 6V output;11A nominal;6-60V input;31.8x43.2x9mm;four2.2mm mounting holes | Vendor documented; verify6V before connecting servos | https://www.pololu.com/product/5673 | 59.95
E38 | 1 | Generic | 2200uF 10V low-ESR electrolytic | Servo rail bulk capacitor | Across6V star after regulator;observe polarity;voltage rating at least10V | Design choice guided by PCA9685 vendor power notes | https://learn.adafruit.com/16-channel-pwm-servo-driver/hooking-it-up | 3
D01 | 1 | Waveshare | 4inch DSI LCD (C) | Optional head display | Round720x720 IPS DSI;126mm outline;101.52mm active;6mm case;four M4 rear bosses on75x75;includes two50mm 15-pin FPC | Vendor documented | https://www.waveshare.com/4inch-dsi-lcd-c.htm | 45
D02 | 1 | Generic | 15-pin 1.0mm pitch FFC type A 800mm | Pi DSI to optional head | Same-side contacts;0.3mm thick;800mm nominal from Pi DSI connector through both arm cable ports;bench-verify signal integrity before closing the arm | Measure route before buying |  | 8
D03 | 1 | Generic | 2-conductor 22AWG silicone lead with2.0mm pitch 4-pin plug | Optional head5V feed | Pi header5V/GND to LCD HP2.0 4-pin;SDA/SCL contacts left empty;800mm | Match plug to purchased LCD connector |  | 4
M01 | 1 | Local metal supplier | Custom ballast disc | Steel ballast plate | Mild steel diameter180 thickness6 mm; 4 holes diameter4.4 at XY(+/-45,+/-35); 4 holes diameter3.4 at XY(+/-26,-36/-8); deburr; approx1.19kg | Custom drawing geometry only | https://www.onlinemetals.com/ | 25
M02 | 1 | Generic | 6808-2RS | Yaw support bearing | 40mm bore x52mm OD x7mm width; sealed deep groove | Measure fit coupon then ream printed seat as needed | https://www.skf.com/group/products/rolling-bearings/ball-bearings/deep-groove-ball-bearings | 12
M03 | 4 | Generic | M4x25 | Base and tray bolts | M4 x25 socket head; steel plate6 + floor3 + spacer5 + tray3 | Nominal stack specified |  | 0.25
M04 | 4 | Generic | M4x5 spacer | Tray standoffs | Metal spacer5mm length; 4.3mm bore; OD8 minimum | Do not substitute compressible foam |  | 0.4
M05 | 4 | Generic | M4 nut | M4 lock nuts | ISO metric nyloc |  |  | 0.12
M06 | 8 | Generic | M4 washer | M4 load spreading washers | OD12 minimum |  |  | 0.06
M07 | 4 | Generic | M3x16 | Yaw cradle through bolts | Through printed cradle3 steel6 and base3; nuts below base; tray has7mm head access | Check underside clearance to desk |  | 0.16
M08 | 2 | Generic | M3x50 | Yaw rear body clamp bolts | Through bottom3 + body40.5 + keeper2.6; do not overtighten case | Body clamp avoids loading the servo mounting ears |  | 0.3
M09 | 2 | Generic | M3x60 | Shoulder clamp bolts | Clamp through the52mm tower width and keeper plus nuts |  |  | 0.4
M10 | 4 | Generic | M3x16 | Shoulder foot bolts | 6mm tower foot plus6mm platform plus nuts |  |  | 0.16
M11 | 6 | Generic | M3x70 | Arm link through bolts | 5+52+5mm stack plus nut;3 per link at X35 and around each servo block | All threads clear rotating hardware |  | 0.45
M12 | 8 | Generic | M3x12 nominal with matching nuts | DS3218 straight-horn attachment sets | Two per joint through adjustable printed slots; actual supplied horn hole size and thread are not documented | Measure each inventory horn before selecting final diameter length and nut arrangement | https://images-na.ssl-images-amazon.com/images/I/81Lbgu%2BnG6L.pdf | 0.25
M14 | 6 | Generic | M3x12 | Base lid screws | Into2.8mm plastic-thread-forming printed pilots |  |  | 0.15
M15 | 4 | Generic | M3x12 | Head yoke screws | 6mm fork mounting face +3mm shell floor; nuts on inside | Check rear boss screw clearance |  | 0.15
M16 | 8 | Generic | M3x10 | Outer bezel screws | 4mm bezel +1mm shim;2.8mm plastic-thread-forming pilot | Tighten evenly to avoid diffuser distortion |  | 0.15
M17 | 4 | Generic | M3x12 | Central face screws | 4mm plate +1mm shim;2.8mm plastic-thread-forming pilot | Keep flange captured with0.2mm clearance |  | 0.15
M18 | 4 | Generic | M3x10 | White ring carrier screws | 2mm carrier on dedicated radius45 bosses at z32.5 | No shared LCD post intersections |  | 0.15
M19 | 4 | Generic | M3x25 | LCD cradle and retaining plate screws | 3mm retainer +15mm cradle; thread into head pillar at z14 | Use foam only on PCB edges; avoid display glass pressure |  | 0.2
M20 | 12 | Generic | M3x1 shim | Precision axial shims | M3 bore; thickness1mm;12 under face and bezel | Thickness controls axial stack |  | 0.12
M21 | 20 | Generic | M2.5x6 | Pedestal sensor board screws | Four per Adafruit3967 board into2.1mm blind pilots;20.32x12.70mm pattern | Start by hand and stop before the PCB bends |  | 0.12
M24 | 30 | Generic | M3 nut | General M3 nuts | Include spare quantities for clamps horn interfaces and platform |  |  | 0.1
M25 | 50 | Generic | M3 washer | General M3 flat washers | Nominal0.5mm; not replacement for1mm axial shims |  |  | 0.05
M26 | 4 | Generic | M2.5x6 | Raspberry Pi fasteners | Pi4 four mounting holes; printed standoffs may be tappedM2.5 | Do not force screws against board components |  | 0.12
M27 | 4 | Generic | Rubber feet | Adhesive anti slip feet | 20mm diameter x5mm high minimum; place radius90 | Provides underside fastener clearance |  | 0.4
M28 | 1 | Generic | Translucent PETG | Frosted optical printing filament | Natural/translucent; approximately60g including trials; solid1.2mm optical skin | Sand600-1000grit and test diffusion |  | 20
M29 | 1 | Generic | PETG | Structural filament | Approx1kg roll; actual slicer mass varies;6 walls on the arm link halves | Do not substitute brittle resin on structural joints |  | 22
M30 | 1 | Generic | Neutral cure silicone | Small adhesive tube | 3 small removable dots for inner diffuser; electronics compatible | Do not cover any optical aperture |  | 6
M31 | 1 | Generic | Thin PCB foam | Closed cell foam tape | 0.5 and1mm thickness; LCD edge preload only | Set LCD stack with measured sample |  | 4
M32 | 1 | Generic | LED retaining tape | Electronics compatible thin adhesive strips | Attach LED ring PCB on support posts without covering LED optics |  |  | 3
M33 | 1 | Generic | Desk clamp | Optional commercial padded desk clamp | Use only if assembly reach/mass exceeds validated stable envelope; not a printed load bearing clamp | Clamp base rim without crushing printed walls |  | 12
M34 | 12 | Generic | M2.5x12 | Optional harness clip screws | For6 printed cable saddles; use selftapped pilots or cableties |  |  | 0.12
M35 | 3 | Generic | 625-2RS | Pitch-joint idler bearings | 5mm bore x16mm OD x5mm width; sealed | Press into16.2mm coupon and link/yoke pockets without loading the inner race |  | 3
M36 | 3 | Generic | M5x16 shoulder bolt or precision-shank bolt | Pitch-joint idler axles | Smooth5mm shank across each625 inner race; one shoulder elbow wrist | Confirm shank and thread lengths against actual bearing and captive nut |  | 0.8
M37 | 3 | Generic | M5 nyloc nut | Pitch-joint captive idler nuts | ISO metric; one in each printed hex trap | Must seat fully without splitting printed boss |  | 0.2
M38 | 6 | Generic | M5 washer | Idler bearing thrust washers | One each side of every625 inner race; thin hardened steel | Must not rub bearing outer race |  | 0.12
D10 | 4 | Generic | M4x8 | Optional LCD carrier to display screws | Through5mm carrier pad into the4mm deep M4 case bosses; longer screws bottom out | Do not exceed8mm; check engagement on the purchased display |  | 0.15
D11 | 4 | Generic | M3x8 | Optional carrier to shell screws | Into2.8mm printed pilots at(+/-55,+/-38) top20.5 | Accessible from the front with the display fitted |  | 0.15
D12 | 4 | Generic | M3x12 | Optional face ring screws | 4mm ring +1mm shim;2.8mm pilots at radius67.8 | Keep flange captured with0.2mm clearance |  | 0.15
D14 | 1 | Generic | Thin closed cell foam tape | Optional LCD rim preload | 0.5mm between the display case rim and the face ring; also under the carrier pads if the boss ends are not coplanar | Set with the purchased display |  | 2

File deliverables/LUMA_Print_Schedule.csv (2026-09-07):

drawing | quantity | variant | stl | name | material | orientation | layer_mm | walls | infill_percent
P01 | 1 | standard | stl/base_tub.stl | Weighted base enclosure with five internal ToF mounts | PETG | floor down | 0.2 | 4 | 25
P02 | 1 | standard | stl/base_lid.stl | Vented base lid and yaw bearing seat | PETG | flat annulus down | 0.2 | 4 | 25
P03 | 1 | standard | stl/electronics_tray.stl | Universal electronics tray with Pi4 standoffs | PETG | plate down | 0.2 | 4 | 25
P04 | 1 | standard | stl/yaw_mount.stl | DS3218MG yaw servo rear-body cradle | PETG | base down | 0.2 | 4 | 25
P05 | 1 | standard | stl/yaw_cap.stl | Yaw clamp keeper | PETG | flat down | 0.2 | 4 | 25
P06 | 1 | standard | stl/turntable.stl | Bearing-supported yaw turntable for straight servo arm | PETG | neck down | 0.2 | 4 | 25
P07 | 1 | standard | stl/shoulder_tower.stl | DS3218MG shoulder body tower with idler support | PETG | foot down | 0.2 | 4 | 25
P08 | 1 | standard | stl/shoulder_cap.stl | Shoulder clamp keeper | PETG | flat down | 0.2 | 4 | 25
P09 | 1 | standard | stl/upper_arm_left.stl | Upper arm enclosed link, idler half | PETG | plate down | 0.2 | 6 | 40
P10 | 1 | standard | stl/upper_arm_right.stl | Upper arm enclosed link, driven half | PETG | plate down | 0.2 | 6 | 40
P11 | 1 | standard | stl/forearm_left.stl | Forearm enclosed link, idler half | PETG | plate down | 0.2 | 6 | 40
P12 | 1 | standard | stl/forearm_right.stl | Forearm enclosed link, driven half | PETG | plate down | 0.2 | 6 | 40
P13 | 3 | standard | stl/horn_spacer.stl | DS3218 straight-horn to driven-link spacer | PETG | flat down | 0.2 | 4 | 25
P14 | 1 | standard | stl/head_yoke.stl | Head tilt fork with driven and 625-idler ears | PETG | rear mounting plate on bed; rotate180X | 0.2 | 4 | 25
P15 | 1 | standard | stl/head_shell.stl | Optical head rear enclosure | PETG | rear disc down | 0.2 | 4 | 25
P16 | 1 | standard | stl/outer_bezel.stl | Outer RGB diffuser retaining bezel | PETG | front lip down | 0.2 | 4 | 25
P17 | 1 | standard | stl/face_center.stl | Central optical baffle plate | black PETG | flat front down | 0.2 | 4 | 25
P18 | 1 | standard | stl/white_carrier.stl | White ring carrier and mounting arms | PETG | flat down | 0.2 | 4 | 25
P19 | 1 | standard | stl/lcd_cradle.stl | 55 mm LCD edge cradle | PETG | flat base down | 0.2 | 4 | 25
P20 | 1 | standard | stl/lcd_retainer.stl | LCD PCB corner retaining plate | black PETG | flat down | 0.2 | 4 | 25
P21 | 1 | standard | stl/outer_diffuser.stl | Frosted outer RGB annular diffuser | natural/translucent PETG | smooth optical face on bed | 0.15 | 3 | 100
P22 | 1 | standard | stl/inner_diffuser.stl | Frosted inner RGBW light diffuser | natural/translucent PETG | smooth optical face on bed | 0.15 | 3 | 100
P23 | 6 | standard | stl/cable_clip.stl | Harness saddle clip | PETG | flat down | 0.2 | 4 | 25
P24 | 1 | standard | stl/fit_coupon.stl | Fastener, 625 bearing and horn-slot clearance coupon | PETG | flat down | 0.2 | 4 | 25
P25 | 1 | dsi-head | stl/head_shell_dsi.stl | Optional DSI head rear enclosure | PETG | rear disc down | 0.2 | 4 | 25
P26 | 1 | dsi-head | stl/lcd4_carrier.stl | Optional 4 inch LCD carrier plate | PETG | flat down | 0.2 | 4 | 25
P27 | 1 | dsi-head | stl/face_ring_dsi.stl | Optional DSI face ring | black PETG | flat front down | 0.2 | 4 | 25

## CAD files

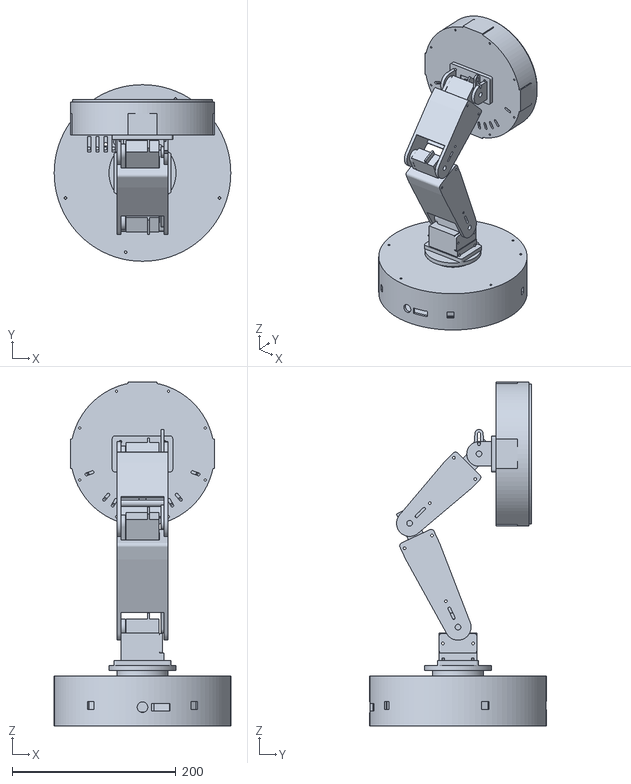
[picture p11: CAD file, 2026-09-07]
cad/visual_only/assembled_reference_dsi_DO_NOT_PRINT.stl
216.0 x 216.0 x 420.7

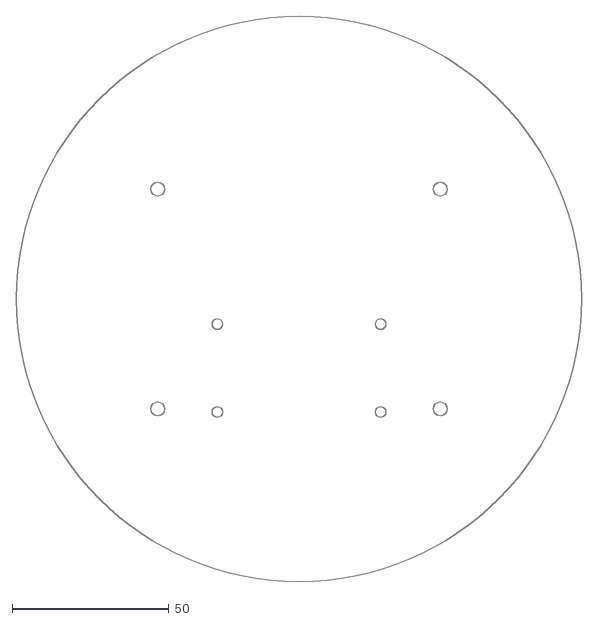
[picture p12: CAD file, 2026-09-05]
cad/ballast_plate.dxf
180.0 x 180.0

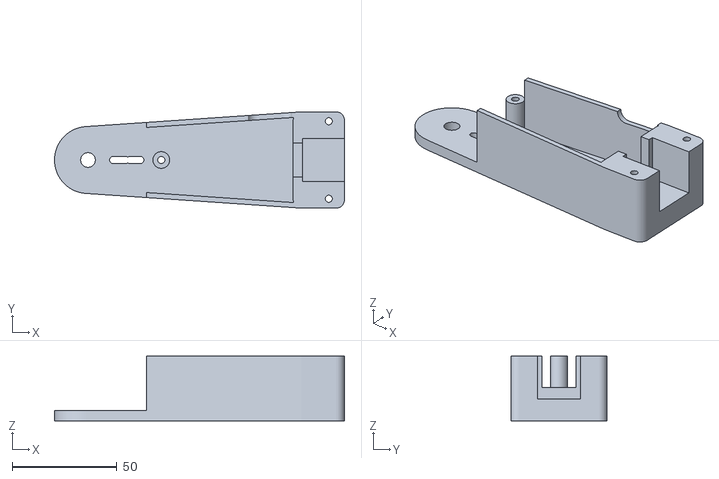
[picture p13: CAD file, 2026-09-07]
cad/stl/upper_arm_right.stl
138.5 x 46.0 x 31.0

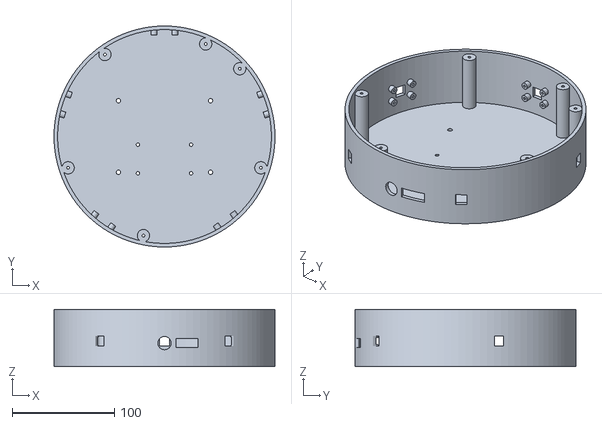
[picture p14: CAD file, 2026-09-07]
cad/stl/base_tub.stl
216.0 x 216.0 x 56.0

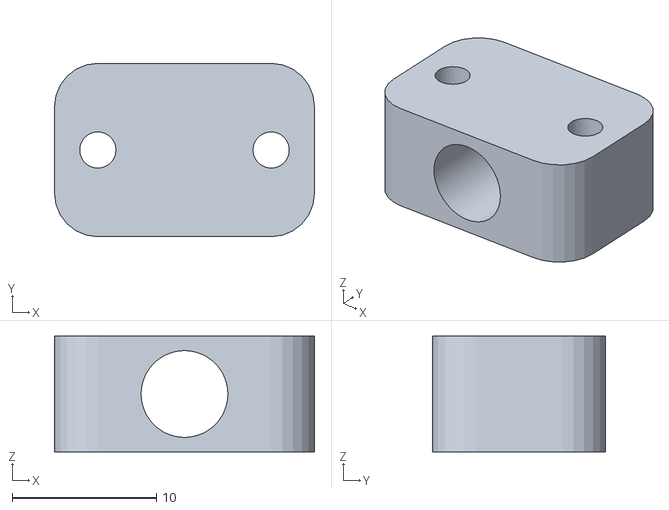
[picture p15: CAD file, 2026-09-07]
cad/stl/cable_clip.stl
18.0 x 12.0 x 8.00

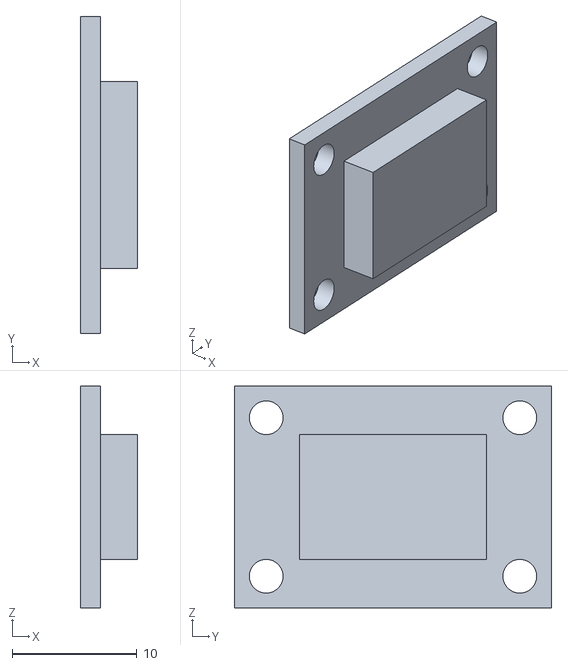
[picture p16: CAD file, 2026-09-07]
cad/visual_only/tof_board_envelope.stl
4.60 x 25.4 x 17.8

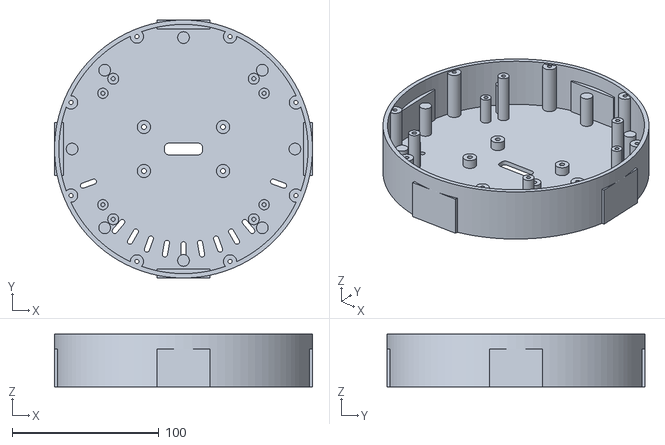
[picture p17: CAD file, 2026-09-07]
cad/stl/head_shell_dsi.stl
176.0 x 176.0 x 36.0

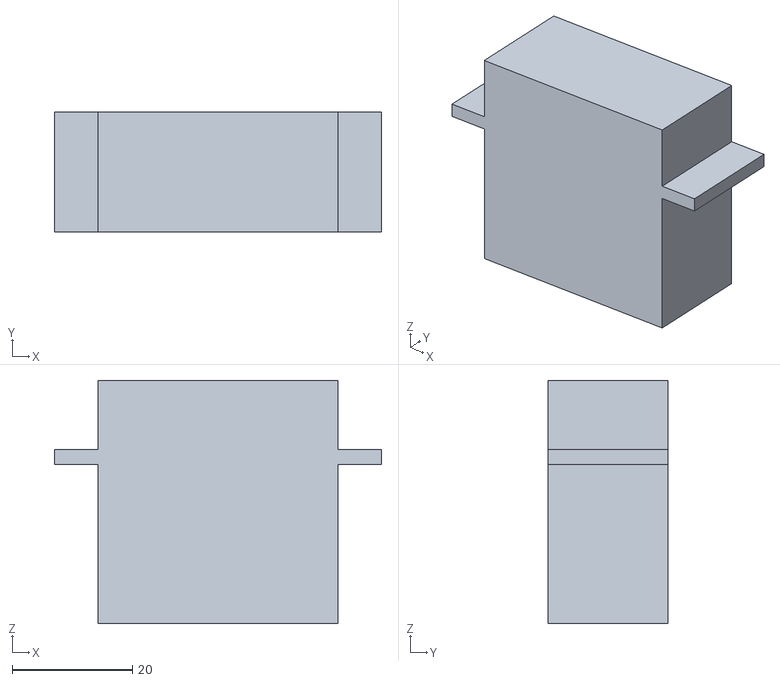
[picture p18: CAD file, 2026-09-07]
cad/visual_only/ds3218_envelope.stl
54.5 x 20.0 x 40.5

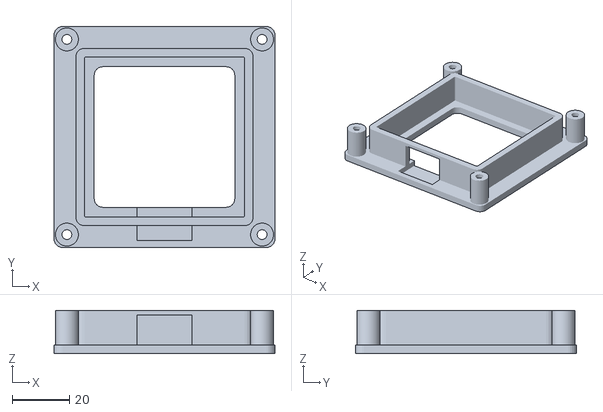
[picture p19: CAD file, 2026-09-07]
cad/stl/lcd_cradle.stl
77.0 x 77.0 x 15.0

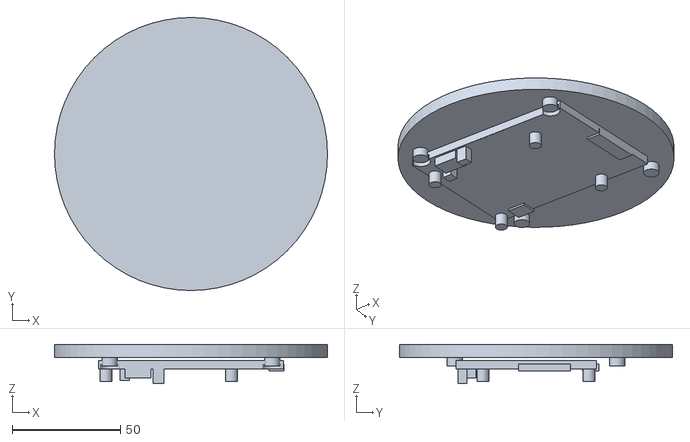
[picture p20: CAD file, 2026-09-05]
cad/visual_only/lcd4_envelope.stl
126.0 x 126.0 x 18.2

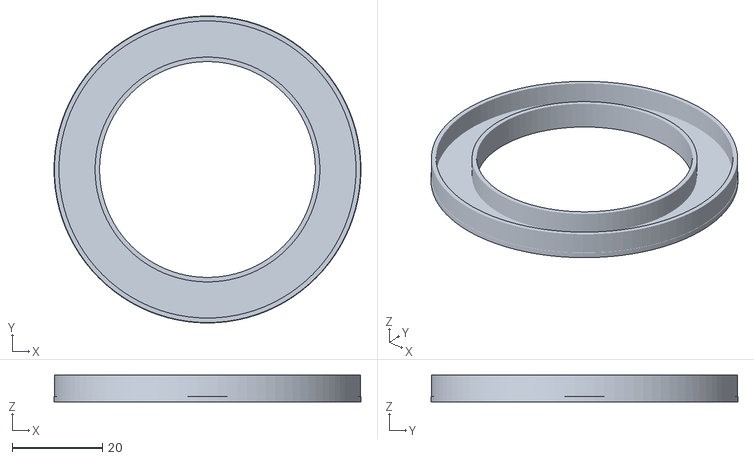
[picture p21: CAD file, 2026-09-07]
cad/stl/inner_diffuser.stl
68.0 x 68.0 x 5.90

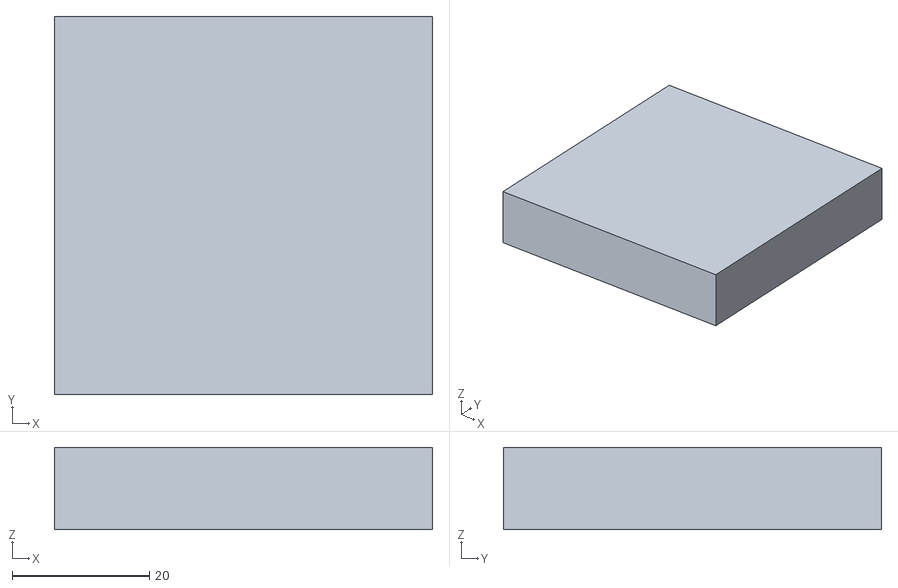
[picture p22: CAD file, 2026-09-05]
cad/visual_only/lcd_board_envelope.stl
55.0 x 55.0 x 12.0

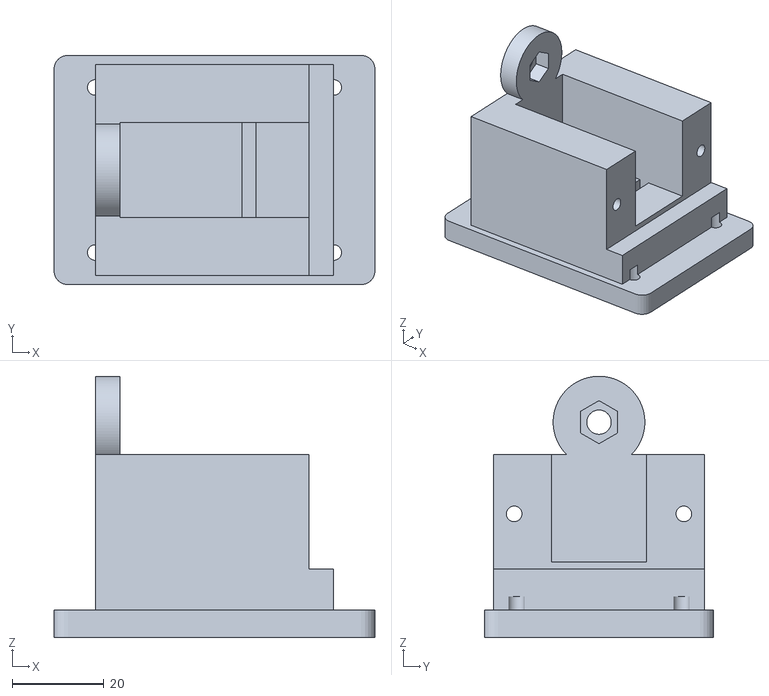
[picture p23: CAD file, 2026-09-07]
cad/stl/shoulder_tower.stl
70.0 x 50.0 x 57.0

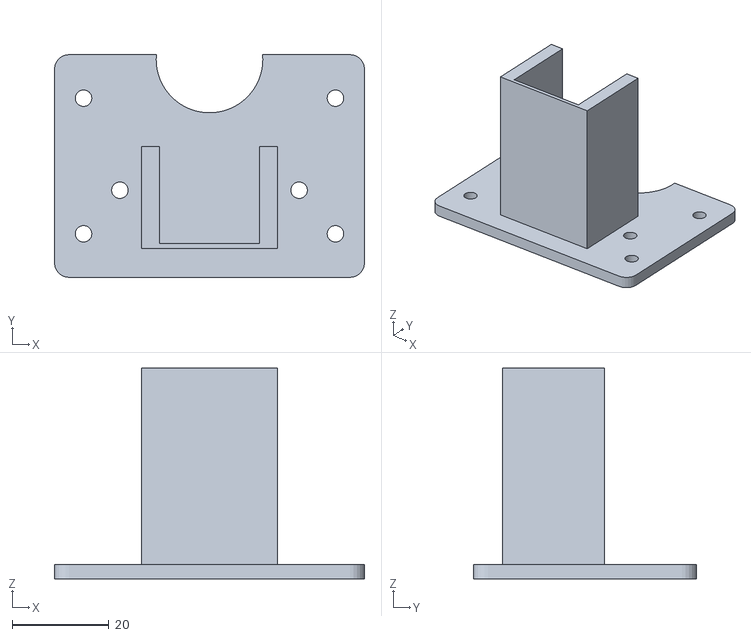
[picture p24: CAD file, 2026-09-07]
cad/stl/yaw_mount.stl
64.0 x 46.0 x 43.5

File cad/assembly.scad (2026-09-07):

// Full assembled STL preview (standard); regenerate with build.py. Units mm.
color([0.8, 0.83, 0.81]) multmatrix([[1.0, 0.0, 0.0, 0.0], [0.0, 1.0, 0.0, 0.0], [0.0, 0.0, 1.0, 0.0], [0.0, 0.0, 0.0, 1.0]]) import("stl/base_tub.stl");
color([0.08, 0.11, 0.12]) multmatrix([[6.123233995736766e-17, -1.0, 0.0, 6.0620016557793985e-15], [1.0, 6.123233995736766e-17, 0.0, 99.0], [0.0, 0.0, 1.0, 25.0], [0.0, 0.0, 0.0, 1.0]]) import("visual_only/tof_board_envelope.stl");
color([0.08, 0.11, 0.12]) multmatrix([[-0.9510565162951535, -0.3090169943749475, 0.0, -94.1545951132202], [0.3090169943749475, -0.9510565162951535, 0.0, 30.592682443119802], [0.0, 0.0, 1.0, 25.0], [0.0, 0.0, 0.0, 1.0]]) import("visual_only/tof_board_envelope.stl");
color([0.08, 0.11, 0.12]) multmatrix([[-0.5877852522924732, 0.8090169943749473, 0.0, -58.19073997695485], [-0.8090169943749473, -0.5877852522924732, 0.0, -80.09268244311978], [0.0, 0.0, 1.0, 25.0], [0.0, 0.0, 0.0, 1.0]]) import("visual_only/tof_board_envelope.stl");
color([0.08, 0.11, 0.12]) multmatrix([[0.5877852522924729, 0.8090169943749476, 0.0, 58.190739976954816], [-0.8090169943749476, 0.5877852522924729, 0.0, -80.09268244311981], [0.0, 0.0, 1.0, 25.0], [0.0, 0.0, 0.0, 1.0]]) import("visual_only/tof_board_envelope.stl");
color([0.08, 0.11, 0.12]) multmatrix([[0.9510565162951535, -0.3090169943749474, 0.0, 94.1545951132202], [0.3090169943749474, 0.9510565162951535, 0.0, 30.59268244311979], [0.0, 0.0, 1.0, 25.0], [0.0, 0.0, 0.0, 1.0]]) import("visual_only/tof_board_envelope.stl");
color([0.8, 0.83, 0.81]) multmatrix([[1.0, 0.0, 0.0, 0.0], [0.0, 1.0, 0.0, 0.0], [0.0, 0.0, 1.0, 54.0], [0.0, 0.0, 0.0, 1.0]]) import("stl/base_lid.stl");
color([0.08, 0.11, 0.12]) multmatrix([[1.0, 0.0, 0.0, 0.0], [0.0, 1.0, 0.0, 0.0], [0.0, 0.0, 1.0, 14.0], [0.0, 0.0, 0.0, 1.0]]) import("stl/electronics_tray.stl");
color([0.08, 0.11, 0.12]) multmatrix([[1.0, 0.0, 0.0, 0.0], [0.0, 1.0, 0.0, 0.0], [0.0, 0.0, 1.0, 9.0], [0.0, 0.0, 0.0, 1.0]]) import("stl/yaw_mount.stl");
color([0.08, 0.11, 0.12]) multmatrix([[1.0, 0.0, 0.0, 0.0], [0.0, 1.0, 0.0, 0.0], [0.0, 0.0, 1.0, 52.5], [0.0, 0.0, 0.0, 1.0]]) import("stl/yaw_cap.stl");
color([0.08, 0.11, 0.12]) multmatrix([[1.0, 0.0, 0.0, 0.0], [0.0, 1.0, 0.0, 0.0], [0.0, 0.0, 1.0, 53.0], [0.0, 0.0, 0.0, 1.0]]) import("stl/turntable.stl");
color([0.8, 0.83, 0.81]) multmatrix([[1.0, 0.0, 0.0, 0.0], [0.0, 1.0, 0.0, 0.0], [0.0, 0.0, 1.0, 74.0], [0.0, 0.0, 0.0, 1.0]]) import("stl/shoulder_tower.stl");
color([0.08, 0.11, 0.12]) multmatrix([[0.0, 0.0, 1.0, 20.6], [1.0, 0.0, 0.0, 0.0], [0.0, 1.0, 0.0, 101.0], [0.0, 0.0, 0.0, 1.0]]) import("stl/shoulder_cap.stl");
color([0.8, 0.83, 0.81]) multmatrix([[0.0, 0.0, 1.0, -31.0], [-0.42261826174069933, -0.90630778703665, 0.0, 0.0], [0.90630778703665, -0.42261826174069933, 0.0, 121.0], [0.0, 0.0, 0.0, 1.0]]) import("stl/upper_arm_left.stl");
color([0.8, 0.83, 0.81]) multmatrix([[0.0, 1.2246467991473532e-16, -1.0, 31.0], [-0.42261826174069933, 0.90630778703665, 1.1099069304367546e-16, 0.0], [0.90630778703665, 0.42261826174069933, 5.1755810150196575e-17, 121.0], [0.0, 0.0, 0.0, 1.0]]) import("stl/upper_arm_right.stl");
color([0.08, 0.11, 0.12]) multmatrix([[0.0, 0.0, 1.0, 22.7], [-0.42261826174069933, -0.90630778703665, 0.0, 0.0], [0.90630778703665, -0.42261826174069933, 0.0, 121.0], [0.0, 0.0, 0.0, 1.0]]) import("stl/horn_spacer.stl");
color([0.8, 0.83, 0.81]) multmatrix([[0.0, 0.0, 1.0, -31.0], [0.7071067811865476, -0.7071067811865476, 0.0, -59.16655664369791], [0.7071067811865476, 0.7071067811865476, 0.0, 247.883090185131], [0.0, 0.0, 0.0, 1.0]]) import("stl/forearm_left.stl");
color([0.8, 0.83, 0.81]) multmatrix([[0.0, 1.2246467991473532e-16, -1.0, 31.0], [0.7071067811865476, 0.7071067811865476, 8.659560562354934e-17, -59.16655664369791], [0.7071067811865476, -0.7071067811865476, -8.659560562354934e-17, 247.883090185131], [0.0, 0.0, 0.0, 1.0]]) import("stl/forearm_right.stl");
color([0.08, 0.11, 0.12]) multmatrix([[0.0, 0.0, 1.0, 22.7], [0.7071067811865476, -0.7071067811865476, 0.0, -59.16655664369791], [0.7071067811865476, 0.7071067811865476, 0.0, 247.883090185131], [0.0, 0.0, 0.0, 1.0]]) import("stl/horn_spacer.stl");
color([0.8, 0.83, 0.81]) multmatrix([[-1.0, -7.498798913309288e-33, 1.2246467991473532e-16, -4.408728476930472e-15], [1.2246467991473532e-16, -6.123233995736766e-17, 1.0, 10.686257098687797], [0.0, 1.0, 6.123233995736766e-17, 332.7359039275167], [0.0, 0.0, 0.0, 1.0]]) import("stl/head_yoke.stl");
color([0.08, 0.11, 0.12]) multmatrix([[-3.749399456654644e-33, -6.123233995736766e-17, 1.0, 22.699999999999996], [0.0, -1.0, -6.123233995736766e-17, 25.686257098687793], [1.0, 0.0, 3.749399456654644e-33, 332.7359039275167], [0.0, 0.0, 0.0, 1.0]]) import("stl/horn_spacer.stl");
color([0.8, 0.83, 0.81]) multmatrix([[-1.0, -7.498798913309288e-33, 1.2246467991473532e-16, 0.0], [1.2246467991473532e-16, -6.123233995736766e-17, 1.0, 46.6862570986878], [0.0, 1.0, 6.123233995736766e-17, 332.7359039275167], [0.0, 0.0, 0.0, 1.0]]) import("stl/head_shell.stl");
color([0.8, 0.83, 0.81]) multmatrix([[-1.0, -7.498798913309288e-33, 1.2246467991473532e-16, 4.408728476930472e-15], [1.2246467991473532e-16, -6.123233995736766e-17, 1.0, 82.6862570986878], [0.0, 1.0, 6.123233995736766e-17, 332.7359039275167], [0.0, 0.0, 0.0, 1.0]]) import("stl/outer_bezel.stl");
color([0.08, 0.11, 0.12]) multmatrix([[-1.0, -7.498798913309288e-33, 1.2246467991473532e-16, 4.408728476930472e-15], [1.2246467991473532e-16, -6.123233995736766e-17, 1.0, 82.6862570986878], [0.0, 1.0, 6.123233995736766e-17, 332.7359039275167], [0.0, 0.0, 0.0, 1.0]]) import("stl/face_center.stl");
color([0.08, 0.11, 0.12]) multmatrix([[-1.0, -7.498798913309288e-33, 1.2246467991473532e-16, 3.980102097228898e-15], [1.2246467991473532e-16, -6.123233995736766e-17, 1.0, 79.1862570986878], [0.0, 1.0, 6.123233995736766e-17, 332.7359039275167], [0.0, 0.0, 0.0, 1.0]]) import("stl/white_carrier.stl");
color([0.08, 0.11, 0.12]) multmatrix([[-1.0, -7.498798913309288e-33, 1.2246467991473532e-16, 1.7145055188062944e-15], [1.2246467991473532e-16, -6.123233995736766e-17, 1.0, 60.6862570986878], [0.0, 1.0, 6.123233995736766e-17, 332.7359039275167], [0.0, 0.0, 0.0, 1.0]]) import("stl/lcd_cradle.stl");
color([0.08, 0.11, 0.12]) multmatrix([[-1.0, -7.498798913309288e-33, 1.2246467991473532e-16, 3.5514757175273244e-15], [1.2246467991473532e-16, -6.123233995736766e-17, 1.0, 75.6862570986878], [0.0, 1.0, 6.123233995736766e-17, 332.7359039275167], [0.0, 0.0, 0.0, 1.0]]) import("stl/lcd_retainer.stl");
color([0.87, 0.95, 0.94]) multmatrix([[-1.0, 2.2496396739927864e-32, -1.2246467991473532e-16, 5.143516556418883e-15], [1.2246467991473532e-16, 1.8369701987210297e-16, -1.0, 88.6862570986878], [0.0, -1.0, -1.8369701987210297e-16, 332.7359039275167], [0.0, 0.0, 0.0, 1.0]]) import("stl/outer_diffuser.stl");
color([0.87, 0.95, 0.94]) multmatrix([[-1.0, 2.2496396739927864e-32, -1.2246467991473532e-16, 5.143516556418883e-15], [1.2246467991473532e-16, 1.8369701987210297e-16, -1.0, 88.6862570986878], [0.0, -1.0, -1.8369701987210297e-16, 332.7359039275167], [0.0, 0.0, 0.0, 1.0]]) import("stl/inner_diffuser.stl");
color([0.08, 0.11, 0.12]) multmatrix([[6.123233995736766e-17, -1.0, 0.0, 0.0], [1.0, 6.123233995736766e-17, 0.0, 0.0], [0.0, 0.0, 1.0, 52.5], [0.0, 0.0, 0.0, 1.0]]) import("visual_only/ds3218_envelope.stl");
color([0.08, 0.11, 0.12]) multmatrix([[0.0, 0.0, 1.0, 20.25], [6.123233995736766e-17, -1.0, 0.0, 0.0], [1.0, 6.123233995736766e-17, 0.0, 121.0], [0.0, 0.0, 0.0, 1.0]]) import("visual_only/ds3218_envelope.stl");
color([0.08, 0.11, 0.12]) multmatrix([[0.0, 0.0, 1.0, 20.25], [-0.42261826174069933, -0.90630778703665, 0.0, -59.16655664369791], [0.90630778703665, -0.42261826174069933, 0.0, 247.883090185131], [0.0, 0.0, 0.0, 1.0]]) import("visual_only/ds3218_envelope.stl");
color([0.08, 0.11, 0.12]) multmatrix([[0.0, 0.0, 1.0, 20.25], [0.7071067811865476, -0.7071067811865476, 0.0, 25.686257098687797], [0.7071067811865476, 0.7071067811865476, 0.0, 332.7359039275167], [0.0, 0.0, 0.0, 1.0]]) import("visual_only/ds3218_envelope.stl");
color([0.08, 0.11, 0.12]) multmatrix([[-1.0, -7.498798913309288e-33, 1.2246467991473532e-16, 2.8166876380389124e-15], [1.2246467991473532e-16, -6.123233995736766e-17, 1.0, 69.6862570986878], [0.0, 1.0, 6.123233995736766e-17, 332.7359039275167], [0.0, 0.0, 0.0, 1.0]]) import("visual_only/lcd_board_envelope.stl");

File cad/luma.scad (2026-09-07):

/* LUMA revision C / millimetres / 2026-09-07
   Original parametric mechanical prototype. Vendor metal horns remain installed.
   Revision C: five pedestal-wall ToF mounts and DS3218MG/PCA9685 motion hardware.
   Select part with -D 'part="upper_arm_left"'. STL coordinates are print coordinates.
   See mechanical.md for assembly and fit checks. */
$fn=96;
part="assembly_preview";
base_d=216; head_d=176; upper_pitch=140; forearm_pitch=120;
clearance=0.35; m3=3.4; m5=5.3; servo_back=30;
sensor_angles=[18,90,162,234,306]; sensor_z=25;
sensor_hole_y=10.16; sensor_hole_z=6.35; sensor_board_r=99;
lid_angles=[42,66,126,198,258,342];
module hole(d,h=100){translate([0,0,-1]) cylinder(d=d,h=h);}
module ring(od,id,h){difference(){cylinder(d=od,h=h);hole(id,h+2);}}
module rr(w,h,t,r=3){linear_extrude(t) hull() for(x=[-w/2+r,w/2-r],y=[-h/2+r,h/2-r]) translate([x,y])circle(r=r,$fn=24);}
module rr2(w,h,r=4){hull() for(x=[-w/2+r,w/2-r],y=[-h/2+r,h/2-r]) translate([x,y])circle(r=r,$fn=32);}
module screw4(x,y,d=m3,h=100){for(a=[-x,x],b=[-y,y])translate([a,b,0])hole(d,h);}
module servo_arm_holes(h=20){hole(7,h);hull(){translate([12,0,0])hole(3.4,h);translate([18,0,0])hole(3.4,h);}hull(){translate([20,0,0])hole(3.4,h);translate([25,0,0])hole(3.4,h);}}
module capsule(l,w,t){hull(){cylinder(d=w,h=t);translate([l,0,0])cylinder(d=w,h=t);}}

// Ballast: separate purchased steel disc Ø180 x 6; bolted retention.
// Five Adafruit 3967 boards sit tangent to the inside wall. Their component faces point outward.
module base_sensor_bosses(){for(a=sensor_angles)rotate(a)for(y=[-sensor_hole_y,sensor_hole_y],z=[sensor_z-sensor_hole_z,sensor_z+sensor_hole_z])translate([sensor_board_r,y,z])rotate([0,90,0])cylinder(d=6,h=6.5);}
module base_sensor_cuts(){for(a=sensor_angles)rotate(a){translate([104,0,sensor_z])cube([12,10,10],center=true);for(y=[-sensor_hole_y,sensor_hole_y],z=[sensor_z-sensor_hole_z,sensor_z+sensor_hole_z])translate([sensor_board_r-.5,y,z])rotate([0,90,0])cylinder(d=2.1,h=7.5);}}
module base_tub(){difference(){union(){ring(base_d,base_d-7,56);cylinder(d=base_d,h=3);for(a=lid_angles)rotate(a)translate([99,0,2])cylinder(d=12,h=51);base_sensor_bosses();}for(a=lid_angles)rotate(a)translate([99,0,0])hole(2.8,58);for(x=[-45,45],y=[-35,35])translate([x,y,0])hole(4.4,15);for(x=[-26,26],y=[-36,-8])translate([x,y,0])hole(m3,8);rotate(270)translate([106,0,23])rotate([0,90,0])cylinder(d=13,h=12,center=true);rotate(282)translate([106,0,23])cube([12,23,9],center=true);base_sensor_cuts();}}
module base_lid(){difference(){union(){cylinder(d=base_d,h=5);translate([0,0,5])ring(62,52.15,7);translate([0,0,-2])ring(208.4,204,2.2);}hole(40.8,15);for(a=lid_angles)rotate(a)translate([99,0,0])hole(m3,8);for(x=[-65:10:-25],y=[35,65])translate([x,y,0])cube([4,19,20],center=true);}}
module electronics_tray(){difference(){rr(166,90,3);for(x=[-70:10:70],y=[-30,0,30])translate([x,y,0])hull(){hole(m3,6);translate([5,0,0])hole(m3,6);}for(x=[-45,45],y=[-35,35])translate([x,y,0])hole(4.4,8);for(x=[-26,26],y=[-36,-8])translate([x,y,0])hole(7,8);translate([0,-13,-1])rr(36,54,8);translate([65,0,0])hole(12,6);}for(x=[-81,-32],y=[-20,38])translate([x,y,3])difference(){cylinder(d=7,h=6);hole(2.1,8);}}
module yaw_mount(){difference(){union(){translate([0,-22,0])rr(64,46,3);translate([-14,-39,3])cube([28,21,40.5]);}translate([-10.35,-38,3])cube([20.7,50,46]);hole(22,8);for(x=[-26,26],y=[-36,-8])translate([x,y,0])hole(m3,8);for(x=[-18.5,18.5])translate([x,-27,0])hole(m3,50);}}
module yaw_cap(){difference(){translate([0,-30,0])rr(47,16,2.6);for(x=[-18.5,18.5])translate([x,-27,0])hole(m3,8);}}
module turntable(){difference(){union(){translate([0,0,15])ring(82,22,6);ring(39.75,22,15.1);cylinder(d=24,h=3);rotate(90)linear_extrude(3)hull(){circle(d=14);translate([25,0])circle(d=10);}}rotate(90)servo_arm_holes(8);screw4(26,18,3.4,25);}}
module shoulder_tower(){difference(){union(){rr(70,50,6);translate([-26,-23,6])cube([52,46,34]);translate([-26,0,47])rotate([0,90,0])cylinder(d=20,h=5.4);}translate([-20.6,-10.35,16.5])cube([54,20.7,45]);translate([6,-10.35,9.5])cube([3,20.7,32]);translate([20.6,-24,15])cube([10,48,30]);screw4(26,18,m3,10);for(y=[-18.5,18.5])translate([-30,y,27])rotate([0,90,0])cylinder(d=m3,h=65);translate([-27,0,47])rotate([0,90,0])cylinder(d=m5,h=8);translate([-24.8,0,47])rotate([0,90,0])cylinder(d=9.4,h=4.4,$fn=6);}}
module shoulder_cap(){difference(){rr(46,24,4);for(x=[-18.5,18.5])translate([x,0,0])hole(m3,8);}}

// ---- Revision C enclosed links. Each link has an idler half and a driven half, printed plate-down.
// Half = 5 plate + 2.4 walls 26 deep, meeting at the link mid-plane with 52 mm between plates.
// Proximal clevis (x<28) stays open so the previous joint's servo body and block can rotate through it.
// The distal block is the integral servo pocket half (replaces the separate cassette and cap).
plate_t=5; wall_t=2.4; half_w=26; floor_t=5.4; wall_start=28;
module link_profile(l){hull(){circle(r=16);translate([l-29.75,0])rr2(24.5,46,4);}}
module arm_half(l,idler=false){difference(){union(){
  linear_extrude(plate_t)link_profile(l);
  translate([0,0,plate_t])linear_extrude(half_w)intersection(){difference(){link_profile(l);offset(r=-wall_t)link_profile(l);}translate([wall_start,-40])square([l,80]);}
  translate([35,0,plate_t])cylinder(d=8,h=half_w);
  translate([l-29.75,0,plate_t])linear_extrude(half_w)rr2(24.5,46,4);
  if(idler)translate([0,0,plate_t])linear_extrude(floor_t)hull(){translate([l-24,0])circle(r=10);translate([l,0])circle(r=10);}}
 if(idler)translate([0,0,-1])cylinder(d=16.2,h=plate_t+2);else servo_arm_holes(plate_t+2);
 translate([35,0,0])hole(m3,40);
 for(y=[-18.5,18.5])translate([l-25,y,0])hole(m3,40);
 translate([l-37.6,-10.35,plate_t+floor_t])cube([35,20.7,40]);
 translate([l-43,-8,plate_t+11])cube([15,16,24]);
 if(idler){translate([l,0,plate_t-1])cylinder(d=m5,h=floor_t+2);translate([l,0,plate_t+floor_t-4.2])cylinder(d=9.4,h=4.5,$fn=6);}
 translate([l-53,-40,plate_t+half_w])rotate([-90,0,0])hull(){for(x=[-6,6])translate([x,0,0])cylinder(d=9,h=40);}}}
module arm_right(l){mirror([0,1,0])arm_half(l,false);}
module horn_spacer(){difference(){linear_extrude(3.3)hull(){circle(d=14);translate([25,0])circle(d=10);}servo_arm_holes(6);}}
module head_yoke(){difference(){union(){translate([0,0,30])rr(74,44,6);for(x=[-31,26])translate([x,0,15])rotate([0,90,0])linear_extrude(5)hull(){circle(r=15);translate([-15,0])square([15,30],center=true);}}translate([24,0,15])rotate([0,90,0])cylinder(d=16.2,h=10);translate([-33,0,15])rotate([0,90,0])rotate(90)servo_arm_holes(10);translate([0,0,29])screw4(27,15,m3,10);translate([-50,-50,36])cube([100,100,10]);translate([-18.2,-9,29.8])cube([36.4,18,2]);translate([-10,-11,29])cube([5,22,8]);translate([0,0,28])rr(26,8,10);}}
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

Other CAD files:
cad/visual_only/assembled_reference_DO_NOT_PRINT.stl
cad/stl/outer_bezel.stl
cad/stl/turntable.stl
cad/stl/head_yoke.stl
cad/assembly_dsi.scad
cad/stl/base_lid.stl
cad/stl/electronics_tray.stl
cad/stl/face_center.stl
cad/stl/face_ring_dsi.stl
cad/stl/fit_coupon.stl
cad/stl/forearm_left.stl
cad/stl/forearm_right.stl
cad/stl/head_shell.stl
cad/stl/horn_spacer.stl
cad/stl/lcd4_carrier.stl
cad/stl/lcd_retainer.stl
cad/stl/outer_diffuser.stl
cad/stl/shoulder_cap.stl
cad/stl/upper_arm_left.stl
cad/stl/white_carrier.stl
cad/stl/yaw_cap.stl
media/sources/luma_exploded.blend
media/sources/luma_hero.blend

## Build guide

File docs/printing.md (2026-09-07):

# Printing and finishing

## Prepare one interface before a full print run

Use a 0.4 mm nozzle as the baseline. Print the fit coupon supplied with the CAD, measure its holes and pockets with calipers and test the actual fasteners and bearings. This is especially useful for horizontal holes, which can print smaller than their modeled diameters. Keep the slicer at 100% scale; compensate holes locally or revise the relevant CAD clearance rather than scaling the complete machine.

The part manifest gives quantities, material and orientation. The STL orientation is the manufacturing orientation when the manifest identifies it as such. The assembled model is for viewing and should not be sliced as a single object. Check that each sliced part has continuous perimeters and that screw holes remain open.

## Structural material

Use PETG for the first functional build. For the four enclosed arm halves and load-carrying brackets, start with0.20mm layers, six perimeters, six top/bottom layers and40% gyroid infill. Print each half with its5mm plate on the bed. The26mm walls, servo block and through-bolt boss then rise vertically. The idler halves include16.2mm 625 pockets and distal captive-nut bosses; inspect their slicer paths and use local solid infill. Print one idler half and one driven half per link.

For non-load-bearing covers, start with four perimeters, 0.20 mm layers and 20% infill. Use the orientation and support notes specific to each part. Remove supports without gouging bearing seats or the surfaces that locate circuit boards.

The optional4-inch DSI head adds three files: `head_shell_dsi`, `lcd4_carrier` and `face_ring_dsi`. Print them only for that head and omit the six standard-head parts listed in the schedule. Revision C has no `brow_bracket`, `sensor_pod` or `sensor_retainer` print.

PLA can be useful for quick dimension checks, but warm motors, LED boards and sustained joint loads make it a poor default for the final load-carrying structure. A material change also changes shrinkage and fit; repeat the coupon.

## Frosted light covers

Print both annular diffusers in natural translucent PETG. The small ring covers the white LEDs and the large ring covers the RGB LEDs. Use 0.12–0.16 mm layers and a continuous solid optical face. Preserve the modeled thin wall; do not replace it with sparse infill that leaves a visible lattice in the illuminated area.

Make a small test of the intended wall thickness before committing both rings. Translucent filaments vary greatly in pigment and light transmission. A nominal 1.2 mm optical face is a starting point, not a measured optical specification.

Wet-sand the outside very lightly with 600–1000 grit abrasive to obtain a uniform matte surface. Wash and dry the part before installation. Do not sand the locating lip so far that the diffuser becomes loose. Check the result at the firmware's normal brightness limit with the head closed: rings that look uniform in room light can reveal hotspots when lit.

Keep the opaque separator between the two light paths. A black or charcoal separator helps prevent RGB light washing across the face. Leave an air gap between LEDs and diffuser as defined by the head stack. Avoid adhesives that touch the LED emitters or the LCD glass.

## Fasteners and tolerance

Use the specified metal nuts, washers,625 bearings and servo horns. Deburr holes before insertion. Test the16.2mm pocket and horn slots on `fit_coupon`. A bolt must enter a clearance hole by hand. The M5 idler bolt must clamp the bearing inner race without rubbing the outer race. Tighten opposing fasteners alternately and stop before printed layers or a PCB deform.

If a heat-set insert is specified, test the insert type and soldering-iron temperature on scrap from the same filament. Support the boss while inserting it, allow it to cool completely, and confirm the insert is perpendicular. Do not add heat-set inserts to a design location intended for a through-bolt and captive nut.

Press bearing outer races squarely into their stated seats. Apply force to the race being fitted. A bearing that becomes rough after installation is a sign of an undersized or distorted seat; correct the seat before assembling the joint.

## Harness preparation

Make a service loop at each joint, and move the unpowered mechanism through its intended travel while watching the loop. The wire must not become taut, rub a sharp printed edge, enter a gear/horn gap or prevent the joint from reaching its limit. Fit the provided cable guides and add soft sleeving where the harness moves against a surface.

Use flexible stranded wire for moving runs. The five short sensor branches remain fixed in the pedestal. Keep their I2C wiring away from the6V servo distribution and strain-relieve each small connector. A STEMMA QT connector is a signal interconnect, not a high-current power connector.

## Record the first print

Record printer, nozzle, material brand, layer height, wall count, infill, measured coupon hole sizes and any CAD clearance change. Weigh the completed head with its display, lights, screws and wiring. Use the measured head mass when reviewing the arm torque calculation; record the five fixed pedestal sensors with the base mass.

Estimated print duration and filament mass depend on the slicer and printer. The CAD validation report includes geometric volume; the slicer's estimate after applying the actual walls and infill is the useful production estimate.

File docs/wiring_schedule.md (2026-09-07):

# Point-to-point wiring schedule

Use these connection names together with the electrical chapter. Physical Raspberry Pi header numbers and BCM GPIO numbers are explicitly distinguished. Disconnect the supplies while changing wiring. Nets starting with `DSI_` apply only to the optional 4-inch DSI head and replace `FACE_USB`.

| Net | From → to | Cable / connection detail |
| --- | --- | --- |
| 3V3_LOGIC | Raspberry Pi4: physical1 3V3 → Mux5626: VIN | STEMMAQT upstream red. All I2C pullups stay3.3V |
| GND_LOGIC | Raspberry Pi4: physical6 GND → Mux5626: GND | STEMMAQT upstream black. Connect DCSTARground also |
| I2C_SDA | Raspberry Pi4: physical3 BCM2 → Mux5626: SDA | STEMMAQT upstream blue. I2C bus1 at100kHz |
| I2C_SCL | Raspberry Pi4: physical5 BCM3 → Mux5626: SCL | STEMMAQT upstream yellow. I2C bus1 at100kHz |
| TOF_FRONT | Mux5626: port0 → VL53L1X front pedestal: STEMMAQT4pin | 4conductor JSTSH. Address0x29 isolated on channel0; wall angle90deg |
| TOF_FRONT_LEFT | Mux5626: port1 → VL53L1X front-left pedestal: STEMMAQT4pin | 4conductor JSTSH. Wall angle162deg |
| TOF_REAR_LEFT | Mux5626: port2 → VL53L1X rear-left pedestal: STEMMAQT4pin | 4conductor JSTSH. Wall angle234deg |
| TOF_REAR_RIGHT | Mux5626: port3 → VL53L1X rear-right pedestal: STEMMAQT4pin | 4conductor JSTSH. Wall angle306deg |
| TOF_FRONT_RIGHT | Mux5626: port4 → VL53L1X front-right pedestal: STEMMAQT4pin | 4conductor JSTSH. Wall angle18deg; leave every optical aperture clear |
| PWM_VCC | Raspberry Pi4: physical1 3V3 → PCA9685: VCC | 22AWG. Powers controller logic only; never powers a servo |
| PWM_GROUND | DCstar: GND → PCA9685: GND | 18AWG. Common reference to Pi sensor bus and all servo signal returns |
| PWM_SDA | Raspberry Pi4: physical3 BCM2 → PCA9685: SDA | 26AWG. Shared upstream I2C bus; address0x40 |
| PWM_SCL | Raspberry Pi4: physical5 BCM3 → PCA9685: SCL | 26AWG. Shared upstream I2C bus;50Hz PWM configured in software |
| PWM_ENABLE | DCstar: GND → PCA9685: /OE | 26AWG. Active-low output enable held low |
| RGB_DATA3V3 | Raspberry Pi4: physical19 BCM10 MOSI → 74AHCT125: DIP2 1A | 26AWG. Do not connect SPI clock to ring |
| RGB_DATA5V | 74AHCT125: DIP3 1Y → RGB ring quadrant1: DIN via330ohm | 26AWG. Resistor at first ring input |
| RGB_CHAIN1 | RGB quadrant1: DOUT → RGB quadrant2: DIN | solder jumper. Connect common5V andGND at all quadrants |
| RGB_CHAIN2 | RGB quadrant2: DOUT → RGB quadrant3: DIN | solder jumper. Mechanical backing supports solder joints |
| RGB_CHAIN3 | RGB quadrant3: DOUT → RGB quadrant4: DIN | solder jumper. Do not connect lastDOUT back to firstDIN |
| WHITE_DATA3V3 | Raspberry Pi4: physical12 BCM18 PWM0 → 74AHCT125: DIP5 2A | 26AWG. Disable onboard analog audio |
| WHITE_DATA5V | 74AHCT125: DIP6 2Y → 24RGBW inner ring: DIN via330ohm | 26AWG. SeparateGRBW data stream |
| SHIFT_ENABLE | DCstar: GND → 74AHCT125: DIP1 /1OE andDIP4 /2OE | 26AWG. Active outputs; tie both low |
| SHIFT_UNUSED | 5VLED: +5V → 74AHCT125: DIP10 /3OE andDIP13 /4OE | 26AWG. Unused outputs disabled |
| SHIFT_UNUSED_INPUT | DCstar: GND → 74AHCT125: DIP9 3A andDIP12 4A | 26AWG. UnusedDIP8 andDIP11 outputs unconnected |
| SHIFT_SUPPLY | 5VLED: +5V → 74AHCT125: DIP14 VCC | 24AWG. 100nF betweenDIP14 andDIP7 |
| SHIFT_GROUND | DCstar: GND → 74AHCT125: DIP7 GND | 24AWG. Shared reference toPi andboth rings |
| PI_GROUND | Raspberry Pi4: physical9 GND → DCstar: GND | 22AWG. Common ground only; never tie5VLED toPi5V |
| PI_POWER | Pi official supply: USB-C5.1V3A → Raspberry Pi4: USB-Cpower | factory cable. Independent from motor12V |
| FACE_USB | Raspberry Pi4: USB-Aport1 → DisplaySKU28514: USB-C | data cable. Do not add a second5V power feed |
| AUDIO_USB | Raspberry Pi4: USB-Aport3 → USB speaker3369: USB | captive cable. LimitUSB total current toPi specification |
| DC_INPUT | MeanWellGST220A12: R7B+12V → Main15Afuse: input | 16AWG. Use correctparallel contacts from supply drawing |
| DC_MAIN | Main15Afuse: output → DC12Vdistribution: +12V | 16AWG. Supply remains outside printed enclosure |
| DC_RETURN | MeanWellGST220A12: R7Breturn → DCstar: GND | 16AWG. All high-current returns star here |
| STOP_COIL_FEED | DC12Vdistribution: +12V → 0.5Afuse: input | 22AWG. Coil branch |
| STOP_NC1 | 0.5Afuse: output → StopNC1: COM | 22AWG. NoPiGPIO in this branch |
| STOP_COIL_PLUS | StopNC1: NC → Relay: coilpositive | 22AWG. Diodecathode stripe here |
| STOP_COIL_MINUS | Relay: coilnegative → DCstar: GND | 22AWG. Diodeanode here |
| MOTOR_RELAY_IN | DC12Vdistribution: +12V → Relay: COM highcurrent | 16AWG. NOcontact>=15A12VDC |
| MOTOR_RELAY_OUT | Relay: NO highcurrent → Servo regulator7.5Afuse: input | 16AWG. Stop removes regulator input and all motor V+ independent of software |
| SERVO_REG_INPUT | Servo regulator7.5Afuse: output → PololuD42V110F6: VIN | 16AWG. 12V nominal input; mount with airflow |
| SERVO_6V | PololuD42V110F6: VOUT6V → Servo4way fusedstar: input | 16AWG. Verify6V and polarity before connecting any servo |
| SERVO_BULK | Servo6Vstar: +6V/GND → 2200uF10Vcapacitor: +/- | short18AWG. Observe polarity and place near star distribution |
| SERVO_POWER1 | Servo3Afuse1: output → YawDS3218MG: V+ | 18AWG. Separate6V feed; do not carry power through PCA9685 traces |
| SERVO_POWER2 | Servo3Afuse2: output → ShoulderDS3218MG: V+ | 18AWG. Separate6V feed |
| SERVO_POWER3 | Servo3Afuse3: output → ElbowDS3218MG: V+ | 18AWG. Separate6V feed |
| SERVO_POWER4 | Servo3Afuse4: output → WristDS3218MG: V+ | 18AWG. Separate6V feed |
| SERVO_GROUNDS | AllfourDS3218MG: GND → DCstar: GND | 18AWG. One power return per servo; common with PCA9685 logic ground |
| SERVO_PWM1 | PCA9685: channel0 signal → YawDS3218MG: PWM | 26AWG. 500-2500us range;1500us nominal neutral; signal and ground only at controller |
| SERVO_PWM2 | PCA9685: channel1 signal → ShoulderDS3218MG: PWM | 26AWG. Confirm direction before fitting loaded horn |
| SERVO_PWM3 | PCA9685: channel2 signal → ElbowDS3218MG: PWM | 26AWG. Confirm direction before fitting loaded horn |
| SERVO_PWM4 | PCA9685: channel3 signal → WristDS3218MG: PWM | 26AWG. Confirm direction before fitting loaded horn |
| STOP_SENSE | Raspberry Pi4: physical13 BCM27 → StopNC2: COM | 26AWG. External10kohm toPi3.3V |
| STOP_SENSE_RETURN | StopNC2: NC → Raspberry Pi4: physical14 GND | 26AWG. Opencontact orbrokenwire readsstop |
| BUCK_INPUT | DC12Vdistribution: +12V via2Afuse → PololuD24V50F5: VIN | 22AWG. ENleftunconnected |
| BUCK_GND | PololuD24V50F5: GND → DCstar: GND | 22AWG. Shortreturn |
| LED_FUSED | PololuD24V50F5: VOUT5V → 3Afuse: input | 22AWG. Verify5VbeforeconnectingLEDs |
| LED_RGB_POWER | 3Afuse: output5V → Outer60RGB: 5V atoppositequadrants | 22AWG. 1000uF10Vcap at ring |
| LED_WHITE_POWER | 3Afuse: output5V → Inner24RGBW: 5V | 22AWG. 1000uF10Vcap at ring |
| LED_RETURNS | Bothrings: GND → DCstar: GND | 22AWG. KeepLEDreturnseparatefromI2Creturnuntilstar |
| DSI_DATA | Raspberry Pi4: DSI connector → 4inch DSI LCD (C): 15-pin DSI FPC | 15-pin1.0mm FFC800mm type A. Optional head only;replaces FACE_USB;route through both arm cable ports with a service loop at each joint |
| DSI_POWER | Raspberry Pi4: physical4 5V → 4inch DSI LCD (C): HP2.0 4-pin 5V | 22AWG. Optional head only;display draws from the Pi supply in place of the USB display |
| DSI_GROUND | Raspberry Pi4: physical39 GND → 4inch DSI LCD (C): HP2.0 4-pin GND | 22AWG. Optional head only;SDA and SCL contacts of this plug stay empty;touch and backlight use the DSI connector I2C bus10 |

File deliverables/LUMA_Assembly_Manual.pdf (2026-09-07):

LUMA / BUILD MANUAL | REV C · 07 SEP 2026


Digital prototype · dimensions in mm · physical validation required | 01

# LUMA

A little light. A lot of personality.

Printable robotic desk companion

## Illustrated assembly manual + engineering drawings

Raspberry Pi 4 · four DS3218MG/PCA9685 joints · round animated LCD (1.85-inch, or optional 4-inch DSI head) · five pedestal sensors · white light + RGB halo

Revision C / 07 September 2026 / Digital prototype release

Digital prototype · dimensions in mm · physical validation required | 02

# Inside the build

Inside the build | 2
Meet LUMA | 3
System at a glance | 5
Parts and purchasing | 6
Printing and finishing | 13
LUMA mechanical assembly, revision C | 15
LUMA electrical design, revision C | 19
Point-to-point wiring schedule | 22
LUMA Pi4 controller and face firmware | 26
First-build verification and maintenance | 29
Finished design and promotional films | 31
Digital release checks | 34
Component source register | 35


Digital prototype · dimensions in mm · physical validation required | 03

# Meet LUMA

LUMA is a printable Raspberry Pi 4 desk companion with an articulated arm, a circular animated face and two independently controlled light rings. It is an original prototype inspired by the posture and personality of the Autonomous Lamp. It is not a conversion kit for the commercial lamp, and its parts do not claim compatibility with that product.

The head contains a Waveshare ESP32-S3-Touch-LCD-1.85 display, a small white-light ring and a larger RGB halo. The Raspberry Pi makes the behavior decisions. The ESP32-S3 built into the display serves as a graphics peripheral over USB. This preserves the requested Pi 4 control while using the actual QSPI display interface supported by the Waveshare board.

The selected 1.85-inch screen is a 360 × 360 IPS TFT LCD, not an OLED. Its visible circular area is approximately 45.68 mm across. Do not substitute a similarly named Waveshare B, C, AMOLED or bare display module without checking both the mechanical envelope and firmware pin mapping.

Revision C uses four matching on-hand Miuzei DS3218MG 270° servos through the user-selected PCA9685. Each wider enclosed link has a driven straight-horn side and an opposite625-bearing side. All five VL53L1X boards move from external head pods to direct mounts inside the fixed pedestal wall. The optional Waveshare4inch DSI LCD(C) head remains available, keeps the RGB halo, and has no separate white ring.

Optional 4-inch DSI head on the same base and enclosed arm.

## What the prototype does

- Wink: one eye closes briefly, the head makes a small gesture and the halo responds.
- Say Hi: a friendly greeting appears on the face, with an audible greeting through the specified audio hardware.
- Be happy: smiling eyes, a bright expression and a gentle arm gesture.
- Sense five horizontal pedestal sectors using Adafruit VL53L1X STEMMA QT boards on separate I2C multiplexer channels.
- Illuminate the face area with the white channel of a 24-pixel RGBW ring and express color with a separate 60-pixel RGB ring.

The provided behavior software runs locally. A conversational language model, camera, microphone, speech recognition and cloud account are not required by this design.

Digital prototype · dimensions in mm · physical validation required | 04

## What is in the project

The printable STL files and editable CAD define the mechanical prototype. The drawings in the back of this manual document those parts. The bill of materials identifies purchased hardware separately from printed parts. Wiring instructions and software source accompany the manual, along with three rendered promotional videos and their editable production scripts.

The project is a digital prototype release. Mesh and software checks can verify files and logic, but they cannot establish physical fit, holding torque, optical performance or print strength. The first assembled unit is the fit-and-function validation build. Record component revision, printer settings and any measured corrections before duplicating it.

## Design choices that matter during assembly

The 55 mm square display board cannot fit through the small light ring's roughly 52.2 mm center. It is installed behind that ring in a separate plane. Follow the head stack order instead of trying to place all boards side by side.

Each enclosed arm link clamps one DS3218 case between its halves. Its driven side uses the servo's straight metal arm, while a625 bearing supports the opposite side. Insert the captive M5 idler nut, servo, lead and harness before closing the three through bolts. The optional4-inch head mounts its display on a carrier plate attached to the display's M4 bosses.

The large RGB ring consists of four purchased 15-pixel quarter boards. Its printed support carries the mechanical load; the solder bridges only connect the electronics. All four arcs are needed to create the complete 60-pixel ring.

Frosted material belongs only over the light rings. Keep the LCD and five pedestal apertures open. A cover over a ranging sensor can create reflection and crosstalk.

The two NeoPixel rings use different pixel formats. The large ring is RGB and the small ring is RGBW. They use separate data outputs and separate driver objects. The normal brightness limits are part of the power and thermal design.

## Reading the drawings

All mechanical dimensions are in millimeters. STL files do not carry a unit declaration: select millimeters in the slicer and confirm the imported bounding dimensions before printing. Use the drawing's stated scale; page fitting in a PDF viewer changes paper scale. Numerical dimensions and the editable model control geometry.

Purchased circuit boards, bearings, fasteners and servo horns are not printable substitutes. Match the exact part numbers in the bill of materials. Minor manufacturing differences are handled by the stated clearances and the first fit coupon, not by forcing a board into a printed pocket.

## Build sequence

1. Check the purchased component revisions and inspect the dimensioned interfaces.
2. Print and measure the fit coupon, then slice the structural parts and diffusers.
3. Bench-test each electrical subsystem before fitting it into the arm.
4. Mount the five sensors inside the pedestal and assemble the base, joint supports and links with motors unpowered.
5. Assemble the layered head, display and light rings.
6. Route and restrain the wiring, leaving service loops at every moving joint.
7. Center each unloaded PWM servo, calibrate neutral pulses/signs and enable a restricted first movement.
8. Validate sensing, fault response, balance, temperature and the three expressions.

## Reference and attribution

The appearance reference is the Autonomous Lamp. (https://www.autonomous.ai/lamp) The LUMA geometry, manual layout and animations are newly authored for this project. Vendor specifications and documentation are identified in the component source register and bill of materials. Promotional files show the digital prototype, not a filmed or physically tested product.

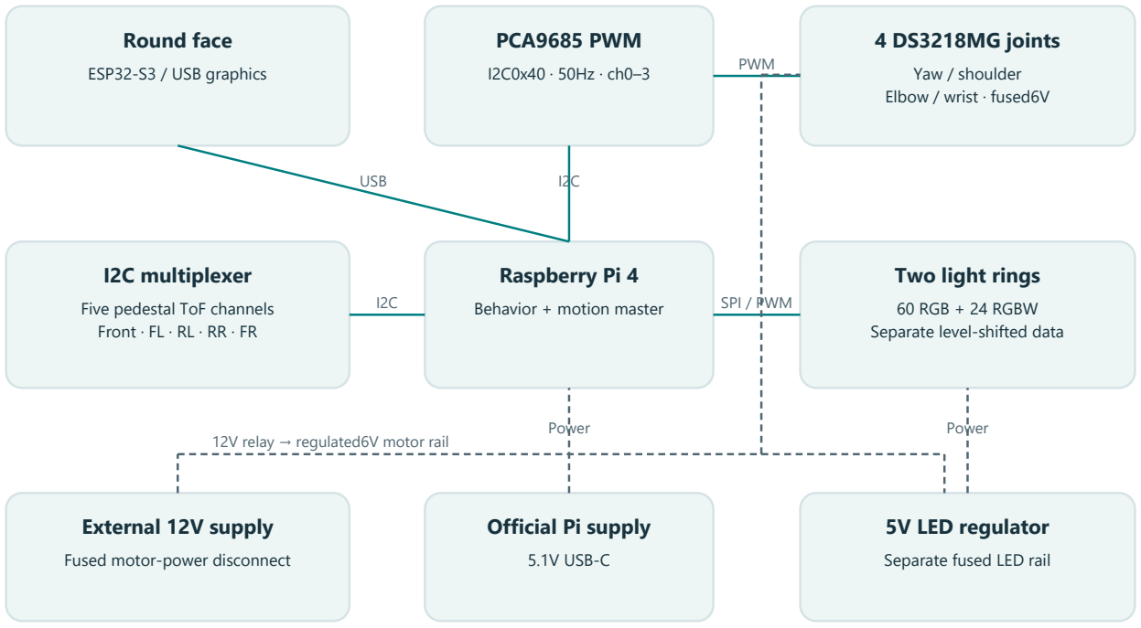
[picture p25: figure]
Raspberry Pi 4; Behavior + motion master; Round face; ESP32-S3 / USB graphics; I2C multiplexer; Five pedestal ToF channels Front · FL · RL · RR · FR; PCA9685 PWM; 4 DS3218MG joints; Yaw / shoulder Elbow / wrist · fused6V; Two light rings; 60 RGB + 24 RGBW Separate level-shifted data; Official Pi supply; 5.1V USB-C; External 12V supply; Fused motor-power disconnect; 5V LED regulator; Separate fused LED rail; USB; PWM; SPI / PWM; Power; 12V relay → regulated6V motor rail

Digital prototype · dimensions in mm · physical validation required | 05

# System at a glance

Solid: data. Dashed: power. Wiring chapter defines grounds, fuses and the motor feed.

The Pi supplies control commands. Dedicated motor and LED power paths keep the actuator load off the Pi's supply. The detailed wiring chapter is authoritative for the power-disconnect circuit and common grounds.

Digital prototype · dimensions in mm · physical validation required | 06

# Parts and purchasing

Planning allowance for the standard build below: US $745.07 before shipping and tax. The optional 4-inch DSI head adds US $60.80 of purchased parts and removes the 1.85-inch display, the inner RGBW ring and their fasteners (about US $68.35). Figures are budgeting allowances, not checked-out prices. Filament and any workshop tools are included only where explicitly listed. Reuse of existing supplies can change the total substantially.

Order the exact display and voltage variant specified. Generic fasteners, connector harnesses, relay contacts and wire must meet the listed dimensions and electrical ratings. Buy the servo horns and their screws with the servos; verify their actual thread and engagement before ordering extras.

Digital prototype · dimensions in mm · physical validation required | 07

## Controller, sensing, lights and power

Ref /
qty
| Item | Required specification | Budget / each
E01 / 1 | Raspberry Pi Raspberry Pi 4 Model B 4GB (https://www.raspberrypi.com/products/raspberry-pi-4-model-b/) | Master controller. 40-pin GPIO and four USB ports | $60.00
E02 / 1 | Raspberry Pi 15W USB-C Power Supply (https://www.raspberrypi.com/products/type-c-power-supply/) | Separate Pi supply. 5.1V 3A USB-C | $12.00
E03 / 1 | Reputable flash vendor 32GB or larger microSD A1 | Operating system card. High endurance preferred | $12.00
E04 / 1 | Waveshare ESP32-S3-Touch-LCD-1.85 SKU28514 (https://docs.waveshare.com/ESP32-S3-Touch-LCD-1.85) | Central face display. 55x55mm;360x360 ST77916 QSPI;USB-C;no B/C suffix | $35.00
E05 / 5 | Adafruit 3967 VL53L1X STEMMA QT (https://www.adafruit.com/product/3967) | Five interaction ranging sensors. 25.5x17.5x4.6mm;I2C0x29

$14.95

E06 / 1 | Adafruit 5626 PCA9548 STEMMA QT (https://www.adafruit.com/product/5626) | Mux for five same-address sensors. TCA9548A-compatible;40.6x20.2x4.8mm;0x70

$6.95

E07 / 5 | Adafruit STEMMA QT JST-SH4 cable (https://www.adafruit.com/category/619) | One separate cable per sensor. Length selected to assembled routing;100-300mm nominal

$2.00

E08 / 1 | Adafruit STEMMA QT to female header cable (https://www.adafruit.com/category/619) | Pi to mux upstream connector. 3.3V logic only | $2.00
E09 / 4 | Adafruit 1768 quarter NeoPixel60 ring (https://www.adafruit.com/product/1768) | Outer RGB emotion halo. 15RGB per quadrant;four form OD157.5mm ID144.8mm ring | $9.95
E10 / 1 | Adafruit 2862 NeoPixel24 RGBW natural white (https://www.adafruit.com/product/2862) | Inner white lamp ring. 24RGBW;OD65.5mm;only W channel used;4500K nominal

$24.95

E11 / 1 | Adafruit 1787 74AHCT125 DIP14 (https://www.adafruit.com/product/1787) | Two data level shifters. 5V VCC;3.3V logic accepted;AHCT required

$1.50

E12 / 2 | Generic 330ohm 0.25W resistor | LED input series resistors. One per independent data line

$0.10

E13 / 2 | Generic 1000uF 10V electrolytic | LED ring supply reservoir. Observe polarity;one each ring

$1.00

E14 / 1 | Generic 100nF ceramic | 74AHCT125 decoupling. Across DIP14 and DIP7 at socket

$0.10

E15 / 1 | Pololu D24V50F5 item2851 (https://www.pololu.com/product/2851) | LED5V buck converter. 5V5A typical thermal-limited;17.8x20.3x8.8mm

$32.95

E16 / 4 | Miuzei DS3218MG 20kg 270-degree (https://images-na.ssl-images-amazon.com/images/I/81Lbgu%2BnG6L.pdf) | Four inventory joint servos. 4.8-6.8V; PWM500-2500us;1500us neutral;50-330Hz;2.2A stall and21.5kg-cm at6.8V;40x20x40.5mm

$0.00

E17 / 1 | Generic PCA9685 16-channel PWM board (https://learn.adafruit.com/16-channel-pwm-servo-driver) | Operator-selected four-servo controller. I2C address0x40;50Hz;channels0-3;3.3V logic VCC;servo V+ supplied separately

$0.00

E18 / 1 | Mean Well GST220A12-R7B (https://www.meanwell.com/Upload/PDF/GST220A/GST220A-SPEC.PDF) | External enclosed motor/LED supply. 12V15A model;R7B powerDIN;keep outside printed enclosure

$95.00

E19 / 1 | Generic Matching R7B powerDIN harness | DC supply breakout. Correct polarity;all specified parallel contacts;15A aggregate rated

$15.00

E20 / 1 | Generic IEC C13 mains cord | External supply cord. Local approved cord;earth conductor intact

$7.00

E21 / 1 | Generic Latching mushroom stop two NC contacts | Motor stop plus isolated Pi sense. NC1 interrupts12V relay coil;NC2 connects BCM27 to GND

$15.00

Digital prototype · dimensions in mm · physical validation required | 08

Ref /
qty
Item | Required specification | Budget / each
E22 / 1 | Generic 12VDC coil relay with30A DC NO contact and
socket | Hardware motor supply disconnect. Coil<=200mA;NO contacts>=15A at12VDC;socket16AWG | $12.00
E23 / 1 | Generic 1N4007 diode | Relay coil flyback. Stripe/cathode to coil positive | $0.10
E24 / 1 | Generic 15A DC fuse and holder | Main12V input branch. Holder and connector rated>=15A | $3.00
E25 / 4 | Generic 3A time-delay DC fuse and holder | Individual6V servo feeds. 18AWG star feeds;one fuse per DS3218

$3.00

E26 / 1 | Generic 2A DC fuse and holder | Buck12V input branch. LED firmware capped20percent | $3.00
E27 / 1 | Generic 7.5A time-delay DC fuse and holder | Servo regulator12V input branch. Between motor relay output and6V regulator VIN;16AWG | $3.00
E28 / 1 | Generic 0.5A DC fuse and holder | Relay coil branch. NC1 switches coil only | $3.00
E29 / 1 | Generic 3A DC fuse and holder | 5V LED output branch. ProtectsLED18-22AWG harness | $3.00
E30 / 1 | Adafruit 3369 mini USB speaker (https://www.adafruit.com/product/3369) | Spoken Hi. USB audio;84x43x32mm;73.6g;keep volume modest | $12.50
E31 / 1 | Generic USB-A to right-angle USB-C data cable | Pi to display. Flexible cable;strain relief;15mm rear plug envelope assumed

$7.00

E33 / 1 Generic 16AWG /18AWG silicone wire and rated distribution terminals

Power harness. 16AWG trunk;18AWG motor branches;22AWGLED branches

$20.00

E34 / 1 | Generic Small perfboard and DIP14 socket | Level shifter assembly. Insulate underside;strain relief all wires

$5.00

E35 / 1 | Generic Pi4 heatsink and ventilation hardware | Thermal management. Check CPU temperature after assembled operation

$7.00

E36 / 1 | Generic 10kohm resistor | External E-stop sense pullup. BCM27 to3.3V;open NC2 means asserted

$0.10

E37 / 1 | Pololu D42V110F6 item5673 (https://www.pololu.com/product/5673) | Servo rail step-down regulator. 6V output;11A nominal;6-60V input;31.8x43.2x9mm;four2.2mm mounting holes

$59.95

E38 / 1 | Generic 2200uF 10V low-ESR electrolytic (https://learn.adafruit.com/16-channel-pwm-servo-driver/hooking-it-up) | Servo rail bulk capacitor. Across6V star after regulator;observe polarity;voltage rating at least10V

$3.00

Digital prototype · dimensions in mm · physical validation required | 09

## Mechanical hardware and consumables

Ref /
qty
Item | Required specification | Budget / each

M01 /
1
Local metal supplier Custom ballast disc (https://www.onlinemetals.com/) | Steel ballast plate. Mild steel diameter180 thickness6 mm; 4 holes diameter4.4 at XY(+/-45,+/-35); 4 holes diameter3.4 at XY(+/-26,-36/-8); deburr; approx1.19kg | $25.00

M02 /
1
Generic 6808-2RS (https://www.skf.com/group/products/rolling-bearings/ball-bearings/deep-groove-ball-bearings) | Yaw support bearing. 40mm bore x52mm OD x7mm width; sealed deep groove

$12.00

M03 /
4
Generic M4x25 | Base and tray bolts. M4 x25 socket head; steel plate6 + floor3 + spacer5 + tray3

$0.25

M04 /
4
Generic M4x5 spacer | Tray standoffs. Metal spacer5mm length; 4.3mm bore; OD8 minimum

$0.40

M05 /
4
Generic M4 nut | M4 lock nuts. ISO metric nyloc | $0.12

M06 /
8
Generic M4 washer | M4 load spreading washers. OD12 minimum | $0.06

M07 /
4
Generic M3x16 | Yaw cradle through bolts. Through printed cradle3 steel6 and base3; nuts below base; tray has7mm head access

$0.16

M08 /
2
Generic M3x50 | Yaw rear body clamp bolts. Through bottom3 + body40.5 + keeper2.6; do not overtighten case

$0.30

M09 /
2
Generic M3x60 | Shoulder clamp bolts. Clamp through the52mm tower width and keeper plus nuts

$0.40

M10 /
4
Generic M3x16 | Shoulder foot bolts. 6mm tower foot plus6mm platform plus nuts

$0.16

M11 /
6
Generic M3x70 | Arm link through bolts. 5+52+5mm stack plus nut;3 per link at X35 and around each servo block

$0.45

M12 /
8
Generic M3x12 nominal with matching nuts (https://images-na.ssl-images-amazon.com/images/I/81Lbgu%2BnG6L.pdf) | DS3218 straight-horn attachment sets. Two per joint through adjustable printed slots; actual supplied horn hole size and thread are not documented

$0.25

M14 /
6
Generic M3x12 | Base lid screws. Into2.8mm plastic-thread-forming printed pilots

$0.15

M15 /
4
Generic M3x12 | Head yoke screws. 6mm fork mounting face +3mm shell floor; nuts on inside

$0.15

M16 /
8
Generic M3x10 | Outer bezel screws. 4mm bezel +1mm shim;2.8mm plastic-thread-forming pilot

$0.15

M17 /
4
Generic M3x12 | Central face screws. 4mm plate +1mm shim;2.8mm plastic-thread-forming pilot

$0.15

M18 /
4
Generic M3x10 | White ring carrier screws. 2mm carrier on dedicated radius45 bosses at z32.5

$0.15

M19 /
4
Generic M3x25 | LCD cradle and retaining plate screws. 3mm retainer +15mm cradle; thread into head pillar at z14

$0.20

M20 /
12
Generic M3x1 shim | Precision axial shims. M3 bore; thickness1mm;12 under face and bezel

$0.12

Digital prototype · dimensions in mm · physical validation required | 10

Ref /
qty
Item | Required specification | Budget / each

M21 /
20
Generic M2.5x6 | Pedestal sensor board screws. Four per Adafruit3967 board into2.1mm blind pilots;20.32x12.70mm pattern | $0.12

M24 /
30
Generic M3 nut | General M3 nuts. Include spare quantities for clamps horn interfaces and platform

$0.10

M25 /
50
Generic M3 washer | General M3 flat washers. Nominal0.5mm; not replacement for1mm axial shims

$0.05

M26 /
4
Generic M2.5x6 | Raspberry Pi fasteners. Pi4 four mounting holes; printed standoffs may be tappedM2.5

$0.12

M27 /
4
Generic Rubber feet | Adhesive anti slip feet. 20mm diameter x5mm high minimum; place radius90

$0.40

M28 /
1
Generic Translucent PETG | Frosted optical printing filament. Natural/translucent; approximately60g including trials; solid1.2mm optical skin

$20.00

M29 /
1
Generic PETG | Structural filament. Approx1kg roll; actual slicer mass varies;6 walls on the arm link halves

$22.00

M30 /
1
Generic Neutral cure silicone | Small adhesive tube. 3 small removable dots for inner diffuser; electronics compatible

$6.00

M31 /
1
Generic Thin PCB foam | Closed cell foam tape. 0.5 and1mm thickness; LCD edge preload only

$4.00

M32 /
1
Generic LED retaining tape | Electronics compatible thin adhesive strips. Attach LED ring PCB on support posts without covering LED optics

$3.00

M33 /
1
Generic Desk clamp | Optional commercial padded desk clamp. Use only if assembly reach/mass exceeds validated stable envelope; not a printed load bearing clamp

$12.00

M34 /
12
Generic M2.5x12 | Optional harness clip screws. For6 printed cable saddles; use selftapped pilots or cableties

$0.12

M35 /
3
Generic 625-2RS | Pitch-joint idler bearings. 5mm bore x16mm OD x5mm width; sealed

$3.00

M36 /
3
Generic M5x16 shoulder bolt or precision-shank bolt | Pitch-joint idler axles. Smooth5mm shank across each625 inner race; one shoulder elbow wrist

$0.80

M37 /
3
Generic M5 nyloc nut | Pitch-joint captive idler nuts. ISO metric; one in each printed hex trap

$0.20

M38 /
6
Generic M5 washer | Idler bearing thrust washers. One each side of every625 inner race; thin hardened steel

$0.12

## Optional 4-inch DSI head (not in the standard total)

Buy these only for the optional head described in the mechanical chapter. With this head, do not buy E04 (1.85-inch display), E10 (24-pixel RGBW ring), E31 (display USB cable), M18 (white ring carrier screws) or M19 (LCD cradle screws).

Digital prototype · dimensions in mm · physical validation required | 11

Ref /
qty
Item | Required specification | Budget /
each
D01 / 1 | Waveshare 4inch DSI LCD (C) (https://www.waveshare.com/4inch-dsi-lcd-c.htm) | Optional head display. Round720x720 IPS DSI;126mm
outline;101.52mm active;6mm case;four M4 rear bosses on75x75;includes two50mm 15-pin FPC

$45.00

D02 / 1 | Generic 15-pin 1.0mm pitch FFC type A 800mm | Pi DSI to optional head. Same-side contacts;0.3mm thick;800mm nominal from Pi DSI connector through both arm cable ports;bench-verify signal integrity before closing the arm

$8.00

D03 / 1 Generic 2-conductor 22AWG silicone lead with2.0mm pitch 4-pin plug

Optional head5V feed. Pi header5V/GND to LCD HP2.0 4-pin;SDA/SCL contacts left empty;800mm

$4.00

D10 / 4 | Generic M4x8 | Optional LCD carrier to display screws. Through5mm carrier pad into the4mm deep M4 case bosses; longer screws bottom out

$0.15

D11 / 4 | Generic M3x8 | Optional carrier to shell screws. Into2.8mm printed pilots at(+/-55,+/-38) top20.5

$0.15

D12 / 4 | Generic M3x12 | Optional face ring screws. 4mm ring +1mm shim;2.8mm pilots at radius67.8

$0.15

D14 / 1 | Generic Thin closed cell foam tape | Optional LCD rim preload. 0.5mm between the display case rim and the face ring; also under the carrier pads if the boss ends are not coplanar

$2.00

## Printable part schedule

24 unique STL files; 31 printed pieces for the standard build, including the fit coupon and optional cable clips. Quantities control the print run. The drawing index uses the same part order.

Drawing / qty | STL identifier | Material / print orientation
P01 / 1 | base_tub | PETG; floor down
P02 / 1 | base_lid | PETG; flat annulus down
P03 / 1 | electronics_tray | PETG; plate down
P04 / 1 | yaw_mount | PETG; base down
P05 / 1 | yaw_cap | PETG; flat down
P06 / 1 | turntable | PETG; neck down
P07 / 1 | shoulder_tower | PETG; foot down
P08 / 1 | shoulder_cap | PETG; flat down
P09 / 1 | upper_arm_left | PETG; plate down
P10 / 1 | upper_arm_right | PETG; plate down
P11 / 1 | forearm_left | PETG; plate down
P12 / 1 | forearm_right | PETG; plate down
P13 / 3 | horn_spacer | PETG; flat down

Digital prototype · dimensions in mm · physical validation required | 12
Drawing / qty | STL identifier | Material / print orientation
P14 / 1 | head_yoke | PETG; rear mounting plate on bed; rotate180X
P15 / 1 | head_shell | PETG; rear disc down
P16 / 1 | outer_bezel | PETG; front lip down
P17 / 1 | face_center | black PETG; flat front down
P18 / 1 | white_carrier | PETG; flat down
P19 / 1 | lcd_cradle | PETG; flat base down
P20 / 1 | lcd_retainer | black PETG; flat down
P21 / 1 | outer_diffuser | natural/translucent PETG; smooth optical face on bed
P22 / 1 | inner_diffuser | natural/translucent PETG; smooth optical face on bed
P23 / 6 | cable_clip | PETG; flat down
P24 / 1 | fit_coupon | PETG; flat down

The optional 4-inch DSI head prints 3 additional files (3 pieces) and omits head_shell, face_center, white_carrier, inner_diffuser, lcd_cradle, lcd_retainer from the list above.

Drawing / qty | STL identifier | Material / print orientation
P25 / 1 | head_shell_dsi | PETG; rear disc down
P26 / 1 | lcd4_carrier | PETG; flat down
P27 / 1 | face_ring_dsi | black PETG; flat front down

Digital prototype · dimensions in mm · physical validation required | 13

# Printing and finishing

## Prepare one interface before a full print run

Use a 0.4 mm nozzle as the baseline. Print the fit coupon supplied with the CAD, measure its holes and pockets with calipers and test the actual fasteners and bearings. This is especially useful for horizontal holes, which can print smaller than their modeled diameters. Keep the slicer at 100% scale; compensate holes locally or revise the relevant CAD clearance rather than scaling the complete machine.

The part manifest gives quantities, material and orientation. The STL orientation is the manufacturing orientation when the manifest identifies it as such. The assembled model is for viewing and should not be sliced as a single object. Check that each sliced part has continuous perimeters and that screw holes remain open.

## Structural material

Use PETG for the first functional build. For the four enclosed arm halves and load-carrying brackets, start with0.20mm layers, six perimeters, six top/bottom layers and40% gyroid infill. Print each half with its5mm plate on the bed. The26mm walls, servo block and through-bolt boss then rise vertically. The idler halves include16.2mm 625 pockets and distal captive-nut bosses; inspect their slicer paths and use local solid infill. Print one idler half and one driven half per link.

For non-load-bearing covers, start with four perimeters, 0.20 mm layers and 20% infill. Use the orientation and support notes specific to each part. Remove supports without gouging bearing seats or the surfaces that locate circuit boards.

The optional4-inch DSI head adds three files: head_shell_dsi, lcd4_carrier and face_ring_dsi. Print them only for that head and omit the six standard-head parts listed in the schedule. Revision C has no brow_bracket, sensor_pod or sensor_retainer print.

PLA can be useful for quick dimension checks, but warm motors, LED boards and sustained joint loads make it a poor default for the final load-carrying structure. A material change also changes shrinkage and fit; repeat the coupon.

## Frosted light covers

Print both annular diffusers in natural translucent PETG. The small ring covers the white LEDs and the large ring covers the RGB LEDs. Use 0.12–0.16 mm layers and a continuous solid optical face. Preserve the modeled thin wall; do not replace it with sparse infill that leaves a visible lattice in the illuminated area.

Make a small test of the intended wall thickness before committing both rings. Translucent filaments vary greatly in pigment and light transmission. A nominal 1.2 mm optical face is a starting point, not a measured optical specification.

Wet-sand the outside very lightly with 600–1000 grit abrasive to obtain a uniform matte surface. Wash and dry the part before installation. Do not sand the locating lip so far that the diffuser becomes loose. Check the result at the firmware's normal brightness limit with the head closed: rings that look uniform in room light can reveal hotspots when lit.

Keep the opaque separator between the two light paths. A black or charcoal separator helps prevent RGB light washing across the face. Leave an air gap between LEDs and diffuser as defined by the head stack. Avoid adhesives that touch the LED emitters or the LCD glass.

## Fasteners and tolerance

Use the specified metal nuts, washers,625 bearings and servo horns. Deburr holes before insertion. Test the16.2mm pocket and horn slots on fit_coupon. A bolt must enter a clearance hole by hand. The M5 idler bolt must clamp the bearing inner race without rubbing the outer race. Tighten opposing fasteners alternately and stop before printed layers or a PCB deform.

If a heat-set insert is specified, test the insert type and soldering-iron temperature on scrap from the same filament. Support the boss while inserting it, allow it to cool completely, and confirm the insert is perpendicular. Do not add heat-set inserts to a design location intended for a through-bolt and captive nut.

Press bearing outer races squarely into their stated seats. Apply force to the race being fitted. A bearing that becomes rough after installation is a sign of an undersized or distorted seat; correct the seat before assembling the joint.

Digital prototype · dimensions in mm · physical validation required | 14

## Harness preparation

Make a service loop at each joint, and move the unpowered mechanism through its intended travel while watching the loop. The wire must not become taut, rub a sharp printed edge, enter a gear/horn gap or prevent the joint from reaching its limit. Fit the provided cable guides and add soft sleeving where the harness moves against a surface.

Use flexible stranded wire for moving runs. The five short sensor branches remain fixed in the pedestal. Keep their I2C wiring away from the6V servo distribution and strain-relieve each small connector. A STEMMA QT connector is a signal interconnect, not a high-current power connector.

## Record the first print

Record printer, nozzle, material brand, layer height, wall count, infill, measured coupon hole sizes and any CAD clearance change. Weigh the completed head with its display, lights, screws and wiring. Use the measured head mass when reviewing the arm torque calculation; record the five fixed pedestal sensors with the base mass.

Estimated print duration and filament mass depend on the slicer and printer. The CAD validation report includes geometric volume; the slicer's estimate after applying the actual walls and infill is the useful production estimate.

Digital prototype · dimensions in mm · physical validation required | 15

# LUMA mechanical assembly, revision C

The editable geometry is cad/luma.scad. cad/build.py exports printable parts, two assembly manifests, purchased-part envelopes, and mesh measurements. Open cad/assembly.scad for the standard head or cad/assembly_dsi.scad for the optional4-inch DSI head. Files under cad/visual_only are not printable parts.

Revision C moves all five Adafruit3967 VL53L1X boards from external head pods to direct mounts behind the pedestal wall. It removes the pod, retainer, and DSI brow-bracket parts and closes the old head penetrations. It also replaces four dual-output ST3215 bus servos with four inventory Miuzei DS3218MG 270-degree PWM servos. The links and yoke are wider, each pitch joint has a625 bearing opposite its single driven horn, and the pedestal/yaw stack is6mm taller. Link pitches, indexed angles, displays, and light-ring geometry remain unchanged.

The indexed neutral has the upper link115° and forearm45° counterclockwise from forward+Y. The relative elbow angle is−70°. Pitch axes run alongX and yaw runs alongZ. Dimensions are: base diameter216mm and wall height56mm; shoulder axisZ121mm; upper pitch140mm; forearm pitch120mm; head diameter176mm and optical depth42mm. The rear head plane center is aboutY46.7mm/Z332.7mm, and the housing top is about420.7mm. Rubber feet add5mm.

## Purchased geometry and fit datums

The Miuzei DS3218 datasheet specifies a40 × 20 × 40.5mm body, 4.8-6.8V PWM control, and a300mm lead. The model uses a conservative body envelope fromX−30..10 relative to the shaft, Y±10, and Z−40.5..0 from the output-side case plane. The mounting-tab envelope is54.5mm long at the datasheet's27.7mm height datum. The included straight metal arm and25T spline stay purchased parts. Its attachment-hole positions and thread are not dimensioned, so the printed driven interfaces use a7mm center clearance and two3.4mm radial slots at12-18mm and20-25mm. Measure the actual horn before selecting bolts. Source: https://images-na.ssl-images-amazon.com/images/I/81Lbgu%2BnG6L.pdf .

Each pitch joint is supported on both sides. The driven plate attaches to the straight metal servo arm through a3.3mm printed spacer. The opposite plate carries a625-2RS bearing, 5mm bore ×16mm OD ×5mm wide. An M5 precision-shank or shoulder bolt clamps only the bearing inner race to a captive M5 nut in the parent idler boss. Use thin thrust washers that do not touch the outer race. The yaw platform remains independently supported by one6808-2RS bearing, 40 ×52 ×7mm.

The Adafruit3967 board outline and four plated holes come from Adafruit's Eagle board file. The board is25.40 ×17.78mm. Its2.5mm holes form a20.32 ×12.70mm pattern centered on the optical package. The pedestal uses four6mm bosses with2.1mm blind pilots per board. The board's component face points outward and its sensor looks through a10 ×10mm open wall aperture. Source: https://github.com/adafruit/Adafruit-VL53L1X-PCB .

The standard display remains the55 ×55mm Waveshare ESP32-S3-Touch-LCD-1.85. It uses a55.8mm edge pocket and foam shims; no guessed board holes. The optional Waveshare4inch DSI LCD(C) remains a round720 ×720 panel in aØ126mm case with four M4 bosses on a75 ×75mm square. Its controller-board/connector envelope is measured from the vendor STEP. Verify every purchased connector and glass projection before tightening.

## Print settings and fit coupon

Print all units in millimeters at100%. The216 ×216mm base leaves only2mm per edge on a220mm bed. Use PETG,0.20mm layers, four walls for general parts, and six walls/40% gyroid for the four link halves and joint supports. The link halves print with their5mm outer plates on the bed. The head yoke prints on its rear mounting plate, rotated180° aboutX, with supports under the fork ears. The removed sensor pods, retainers, and brow bracket are not part of revision C.

Print fit_coupon first. It carries3.0/3.2/3.4/3.6mm bores, the16.2mm 625 pocket, and the DS3218 straight-horn slots. Tune only the affected CAD clearance; never scale the full mechanism. A625 bearing must seat squarely without force through its inner race. Clear through-holes by hand. The2.1mm base sensor and Pi pilots are for carefully started M2.5 screws. Do not force a screw or bend a PCB.

Print the light diffusers in natural/translucent PETG at0.15mm layers, three perimeters, and100% infill. Preserve the1.2mm optical skin. Do not put printed plastic, frosting, adhesive, or an untested IR window over any ToF aperture.

Digital prototype · dimensions in mm · physical validation required | 16

## Prepare metal parts

1. Make theØ180 ×6mm mild-steel ballast from cad/ballast_plate.dxf or the dimensioned SVG. Drill fourØ4.4 holes at(±45,±35) and fourØ3.4 holes at(±26,−36/−8). Deburr and protect it from corrosion. Keep the center solid.
2. Confirm the6808 bearing is40 ×52 ×7mm and all three625 bearings are5 ×16 ×5mm. Test the printed pockets before assembly.
3. Inspect all four inventory DS3218MG units and straight25T arms. Confirm the servo is the270° position variant, not a continuous-rotation unit. Measure the metal-arm hole diameter, spacing, thickness, center-screw engagement, and clearance over the case. Dry-fit each printed radial slot before power is applied.
4. Test each M5 idler stack outside the arm. The smooth bolt section must span the bearing inner race. The washer and printed plate must not touch the rotating outer race. The captive nut must seat without splitting its boss.

## Assemble the pedestal sensors and weighted base

5. Put the steel disc on the3mm base floor. Attach the yaw cradle atZ9 with fourM3x16 bolts through the asymmetric pattern. Keep all underside hardware above the rubber-foot contact plane.
6. Identify front as+Y. The five sensor centers are front90°, front-left162°, rear-left234°, rear-right306°, and front-right18°. Insert oneM2.5x6 screw through each board hole from the PCB's inner side. Put the component face toward its wall opening and start all four screws into the matching blind pilots. Tighten in a cross pattern only until the board cannot rock. Confirm the optical package is centered and unobstructed. Connect one side STEMMA QT socket and strain-relieve the cable inside the wall.
7. Place the yaw DS3218MG with its shaft vertical, its body toward−Y, its case bottom atZ12, and its output-side case plane atZ52.5. The rear-body cradle avoids the servo's mounting ears. Fit the yaw keeper atZ52.5 with twoM3x50 bolts atX±18.5/Y−27. Tighten only enough to secure the case.
8. Mount the electronics tray atZ14 on four5mm metal spacers with fourM4x25 bolts through base, ballast, spacer, and tray. Mount the Pi on its standoffs. Use the universal tray slots for the PCA9685, sensor mux,6V regulator, and insulated distribution hardware; their exact board revisions are not assigned guessed hole coordinates. Keep the regulator ventilated. Keep the external AC adapter and any oversized high-current enclosure outside the compact base.
9. Use the round rear wall port at270° and rectangular port at282° for external power/USB. Add grommets and strain relief. The six lid posts sit at42/66/126/198/258/342° between the sensor sectors and rear ports.
10. Seat the6808 in the lid's52.15mm pocket. The turntable's39.75mm neck passes through its40mm bore. Below the lid, attach the3mm tangential horn web to the yaw servo's straight metal arm through the adjustable slots. The web stays below the lid disk and the neck carries load through the bearing. Verify free±25° yaw before fitting sixM3x12 lid screws. The turntable top and shoulder-tower datum areZ74.

## Assemble the shoulder and enclosed links

Each link has an idler half and a driven half. LocalX runs from proximal pivot to distal servo shaft:140mm for the upper link and120mm for the forearm. The5mm plates occupy assembled Z−31..−26 and+26..+31. Each half has26mm-deep walls that meet atZ0. The DS3218 rear-case pocket is41.2mm across the axis and20.7mm across the body. The walls start atX28, leaving the proximal clevis open. A21 ×9mm cable port remains on the inner wall. ThreeM3x70 bolts close each link: one atX35 and two around the distal block atY±18.5.

The idler half has a16.2mm bearing pocket at its proximal pivot and an M5 captive-nut boss at its distal servo axis. The driven half has the two straight-horn slots at its proximal pivot. The parent servo output-side case plane sits at localZ+20.25. Its metal arm and the3.3mm spacer fill the gap to the driven plate inner face atZ+26. The opposite case face clears the idler boss by0.35mm. These are digital nominal clearances and require a physical fit check.

11. Bolt the shoulder tower to the turntable with fourM3x16 bolts. Fit the shoulder DS3218MG with its shaft atZ121 and its output side toward the driven link half. Install the keeper with twoM3x60 bolts. Insert the first M5 captive nut into the tower idler boss before the upper link blocks access.

Digital prototype · dimensions in mm · physical validation required | 17
12. Press one625 bearing into the proximal pocket of upper_arm_left. Put the inner race against the shoulder idler boss with its thrust washers and M5 axle. Do not tighten the outer race. With the shoulder servo centered and unpowered, index the link at115° and attach upper_arm_right to the straight metal arm through one printed spacer and two measured horn fasteners.
13. Seat the elbow DS3218MG in the upper-link distal pocket with its shaft atX140. Put its output toward the driven half and cable toward the rear relief. Route its lead and the remaining head harness through the inner wall port. Insert the distal M5 captive nut. Close the two halves with threeM3x70 bolts without crushing the case.
14. Assemble the forearm the same way. Its idler625/M5 stack attaches at the elbow, and its driven half attaches to the elbow's straight horn at−70° relative angle. Seat the wrist servo atX120, route its lead, insert the last M5 captive nut, and close with threeM3x70 bolts.
15. The head yoke has one625 idler ear and one tangential straight-horn ear. Attach its bearing side to the forearm idler boss, then attach its driven side to the centered wrist horn through the last3.3mm spacer. At neutral, the broad head plate faces+Y and lies21mm forward of the wrist axis. Verify that the servo mounting tab clears the yoke notch.
16. Pass the head harness through the26 ×8mm yoke slot, over each servo case, and through both link ports. Leave a slack service loop at every joint. No moving wire may enter a horn, bearing, idler bolt, or clamshell seam.

## Assemble the standard 1.85-inch head

Head-localZ starts at the rear face and increases toward the viewer. The shell floor isZ0-3 and rim ends atZ36. There are no sensor mounts or apertures in the revision C head.

17. Attach head_shell to the yoke with fourM3x12 bolts on the54 ×30mm pattern. Bring only display, LED, and optional DSI wiring through the center slot.
18. Join four Adafruit1768 RGB quarter-rings into one60-pixel circle. Dry-fit the158mm OD/145mm ID board on the radius76 posts. Retain the PCB mechanically; solder bridges are electrical joints only.
19. Put the standard LCD cradle on its four headZ14 pillars. Place the55mm board in the55.8mm pocket with thin edge foam and its low-profile USB plug in the19mm relief. Fit the retainer atZ29 with fourM3x25 screws. Do not load the glass.
20. Fit the white-ring carrier on the radius45 bosses atZ32.5 with fourM3x10 screws. Attach the24-pixel RGBW ring without covering LEDs or loading solder joints.
21. Put1mm shims on the four radius60 face bosses and eight radius83 bezel bosses. Fit the outer diffuser, center baffle, and outer bezel without squeezing the optical skin. Secure the center with fourM3x12 and bezel with eightM3x10. Retain the inner diffuser with three small removable neutral-cure silicone dots.

## Assemble the optional 4-inch DSI head

This variant replaces head_shell, face_center, white_carrier, inner_diffuser, lcd_cradle, and lcd_retainer with head_shell_dsi, lcd4_carrier, and face_ring_dsi. It keeps the yoke, outer bezel, outer diffuser, and60-pixel halo. It has no brow bracket or head-mounted sensors and no separate white ring.

22. Attach head_shell_dsi to the yoke with fourM3x12 bolts. Fit the RGB halo on its radius76 posts.
23. Attach lcd4_carrier to the display's four M4 bosses with M4x8 screws. Do not use longer screws. Confirm the PCB, Pi standoffs, power connector, USB-C, and DSI FPC all clear the carrier window.
24. Lower the carrier onto the shell bosses at(±55,±38). Route the800mm DSI FPC and5V/GND lead through the26 ×8mm floor/yoke slots. Secure the carrier with fourM3x8 screws.
25. Put0.5mm foam on the display rim and1mm shims on the face/bezel bosses. Fit the outer diffuser, face_ring_dsi, and bezel. Tighten evenly without pressing the active glass. Configure and test the display before closing the base.

Digital prototype · dimensions in mm · physical validation required | 18

## Bring-up and limits

26. With every horn disconnected from the links, center one servo at a time using the bounded PCA9685 command in software/README.md. Mark its1500µs position. Power off before installing a horn. Set neutral_pulse_us and joint_signs from the actual indexed mechanism; the default values are not physical calibration.
27. Support the head and move each unpowered joint through the intended small range. Check the625 stacks, open clevises, servo tabs, cable loops, and straight horns. Initial commanded limits remain yaw±25° and shoulder/elbow/wrist±10° at12°/s. The supplied digital collision check covers only the indexed pose.
28. Verify the physical motor stop before armed motion. Run one joint and then one complete scene while supported. A PCA9685 check proves controller communication only. The DS3218 provides no position, current, load, or temperature feedback. Measure6V droop, regulator temperature, each accessible servo-case temperature, and joint holding behavior.
29. Recheck clamp, horn, idler, and link fasteners after the first short motion run and first thermal cycle. Stop on noise, binding, rising temperature, visible deflection, or lost PWM control. Physical fit, proof load, drop, fatigue, thermal, optical, and cable-flex tests remain first-build work.

## Load and stability calculations

The documented21.5kg-cm DS3218 stall torque at6.8V is about2.11N·m. Torque at the selected6V rail and continuous safe torque are not documented. Never treat stall torque as a holding-duty rating. A conservative folded standard-head estimate remains about0.40N·m at the shoulder; the optional DSI head estimate remains about0.48N·m. Wider link shells and actual wiring change mass, so weigh the build and repeat the calculation.

With a0.32m horizontal head moment arm, the standard0.40kg head alone produces about1.26N·m; the optional0.50kg head produces about1.57N·m, before link mass and acceleration. That is too close to the servo's6.8V stall rating for claimed continuous operation, and the project runs at6V. The restricted folded pose is deliberate. Reduce reach, add counterbalance, or change the actuator architecture before extended duty.

The1.19kg ballast alone gives a nominal1.26N·m restoring moment about the108mm base radius. This excludes dynamics, cable pulls, foot friction, and the raised center of mass. Use a commercial padded desk clamp if the measured build exceeds the validated stable envelope. This is not a lifting arm.

## Drawing and verification limits

Assembly matrices are row-major4×4 in millimeters. Right-side link halves are rotated180° about their length axis for assembly. Purchased horns, bearings, screws, wiring, and exact PCA9685 geometry are not printable substitutes. validation/assembly_check.json covers printable solids at the indexed pose. cad/purchased_fit.json covers conservative static DS3218, sensor-board, and display envelopes. Neither report certifies moving clearance, strength, electrical safety, or physical fit.

Digital prototype · dimensions in mm · physical validation required | 19

# LUMA electrical design, revision C

The Raspberry Pi 4 is the behavior and motion master. It reads five Adafruit 3967 VL53L1X STEMMA QT sensors through an I2C mux, commands four inventory Miuzei DS3218MG servos through the user-selected PCA9685 PWM board, selects face expressions, produces local speech, and drives both light rings.

The standard head uses the Waveshare ESP32-S3-Touch-LCD-1.85, SKU 28514, without B or C suffix. It is a 360 × 360 TFT LCD, not OLED. Its ESP32-S3 is a USB graphics peripheral; its Wi-Fi, touch, microphone, and battery functions are unused. Do not substitute a visually similar 1.85B, 1.85C, AMOLED, or bare panel. See Waveshare documentation. (https://docs.waveshare.com/ESP32-S3-Touch-LCD-1.85)

Pi4 USB ─┬─ Waveshare ESP32-S3 1.85 LCD / face firmware
└─ USB speaker / local espeak-ng speech
Pi I2C ──┬─ PCA9685 address0x40 ─ PWM channels0..3 ─ four DS3218MG
└─ PCA9548/TCA9548A-compatible mux address0x70 ─ ports0..4 ─ five VL53L1X Pi BCM10 SPI MOSI ─ 74AHCT125 +330Ω ─ 60RGB outer ring
Pi BCM18 PWM0 | ─ 74AHCT125 +330Ω ─ 24RGBW inner ring (white only)
Pi BCM27 | ─ isolated NC stop contact ─ GND
12V relay output ─ 7.5A fuse ─ 6V/11A regulator ─ four fused servo feeds

## Optional 4-inch DSI head

The optional head replaces the USB display with a Waveshare 4inch DSI LCD (C). It is a round 720 × 720 IPS panel in a 126 mm case. The Pi renders the face directly with display_kind: "dsi"; there is no display coprocessor or serial heartbeat. Connect its 15-pin 1.0 mm DSI FPC and connect 5 V/GND from Pi header pins4/39 to the display's HP2.0 socket. Leave that socket's SDA/SCL contacts empty. Touch and backlight control use I2C_bus=10 on the DSI connector, and LUMA does not read touch input.

The FPC run through the arm is about800 mm. That is longer than the vendor-supplied50mm cables and must be proven on the bench before the links close. Keep it away from the moving 6 V servo feeds. This head omits the24-pixel RGBW ring; the outer halo supplies capped white output. Vendor page. (https://www.waveshare.com/4inch-dsi-lcd-c.htm)

## Power, stop, and servo distribution

Use the official Pi5.1 V/3 A USB-C supply. Use the external Mean Well GST220A12-R7B 12 V/15 A supply for the LED buck converter and the servo regulator. The enclosure contains DC only. All grounds meet at one DC star. Pi5 V and LED5 V remain separate. Wire the locking R7B connector exactly as its drawing specifies. Mean Well specification. (https://www.meanwell.com/Upload/PDF/GST220A/GST220A-SPEC.PDF)

The four Miuzei DS3218MG units are 4.8-6.8 V PWM position servos. The vendor datasheet gives 2.2 A stall current and21.5 kg-cm stall torque at6.8 V. Four can therefore demand8.8 A at once. This is an abnormal design transient, not a permitted continuous operating point. Use the Pololu D42V110F6 fixed6 V regulator. Its nominal rating is11 A, while its actual continuous output depends on input voltage, cooling, and load. Verify6 V polarity and loaded voltage before connecting a servo. DS3218 datasheet, (https://images-na.ssl-images-amazon.com/images/I/81Lbgu%2BnG6L.pdf) regulator specification. (https://www.pololu.com/product/5673)

A15 A main fuse protects the12 V trunk. A normally-open12 V relay interrupts only the servo regulator input. A latching stop's first NC contact interrupts the fused relay coil. Its second isolated NC contact grounds BCM27 in the normal state. Add the coil flyback diode with its stripe at coil positive. The stop must remove servo power with the Pi disconnected. Pi, display, sensing, and lights stay powered so they can report a stopped motor rail.

Feed the regulator through its own7.5 A time-delay fuse. Put a2200 µF/10 V or higher low-ESR capacitor across the6 V star. Feed each servo from that star through its own3 A time-delay fuse and18 AWG V+/GND pair. Do not send the possible8.8 A group current through a generic PCA9685 terminal block or PCB trace. At the PCA9685, connect only each servo's signal and ground; route V+ from the fused star. Confirm actual connector polarity instead of relying only on wire color.

Power PCA9685 VCC from Pi3.3 V. Connect SDA/SCL to Pi physical pins3/5, connect its ground to the DC star, and hold active-low /OE low. The PCA9685 address is0x40 and the sensor mux address is0x70. Software uses channels0,1,2,3 for yaw, shoulder, elbow, wrist at50 Hz. The documented DS3218 pulse range is500-2500 µs with1500 µs nominal neutral over the270-degree variant. The PWM board reports I2C communication only. It cannot report servo shaft position, load, current, or temperature. PCA9685 guide. (https://learn.adafruit.com/16-channel-pwm-servo-driver/hooking-it-up)

Digital prototype · dimensions in mm · physical validation required | 20

The Pololu D24V50F5 still converts12 V to the separate LED5 V rail through its2 A input and3 A output fuses. Software caps the outer RGB ring at20%. The outer ring allowance at that cap is about0.72 A. The inner ring uses RGB=0 and W no higher than192/255, about0.36 A. Put a1000 µF/10 V capacitor at each ring and a100 nF ceramic at the74AHCT125. Exact current and temperature require measurement.

## Five pedestal sensors and I2C allocation

All five Adafruit3967 boards mount behind open apertures in the216 mm pedestal wall. Looking down with the face aimed toward+Y, their centers are front90°, front-left162°, rear-left234°, rear-right306°, and front-right18°. Mux ports0 through4 use that same order. The two rear sectors can request a wink. The two front-side sectors can request the happy gesture. Every sector is also a mandatory obstruction input.

Each board remains at address0x29 on its own mux channel. The mux is the Adafruit5626 PCA9548, which uses the TCA9548A-compatible driver. Both the mux and PCA9685 share the upstream Pi I2C bus at3.3 V logic. Put the mux on the electronics tray in the pedestal. The five branch cables now remain in the fixed base and do not pass through yaw or the arm.

Software ranges only one emitter at a time with a33 ms short-mode timing budget. A normal five-channel sweep is about0.25-0.4 seconds. A missing sensor, invalid/no-return value, reading older than650 ms, or valid range below100 mm latches a motion hold. The five narrow horizontal cones do not cover every pinch point and are not a safety-rated perimeter.

Remove each shipping film. Keep every10 × 10 mm wall aperture open; no frosted plastic or uncharacterized IR window belongs in front of the sensor. Mount each25.40 × 17.78 mm board component-side toward its opening using fourM2.5x6 screws on its20.32 × 12.70 mm hole pattern. Tighten only until the PCB is stable. Leave side clearance for one STEMMA QT plug and add strain relief inside the base.

## Motion indexing without joint feedback

The DS3218MG has one25T output spline and no readable position channel. Yaw remains supported by the6808 bearing. Each pitch joint uses the servo's straight metal arm on the driven side and a625 bearing/M5 axle on the opposite side. The supplied metal arm's attachment holes are not dimensioned in the datasheet, so the printed interface has two radial slots. Measure each actual horn and select fasteners before applying load.

Center each disconnected, unloaded servo at1500 µs before installing its horn. The mechanical neutral pose is upper link115° from+Y horizontal, forearm45° from+Y, relative elbow−70°, and face vertical toward+Y. The shoulder axis isZ121 mm after the6 mm pedestal increase. Initial command limits remain yaw±25° and shoulder/elbow/wrist±10°. Calibrate each neutral_pulse_us and joint_signs value from the real mechanism; all1500/all+1 values are only starting values.

Hardware motion stays off unless both calibrated=true and --arm are supplied. Arming verifies fresh sensor data, display health, a closed motor stop, and PCA9685 communication, then sends the four calibrated neutral pulses. It cannot verify the physical starting angles. Support the complete arm before arming because a wrong pulse or horn index can cause immediate motion.

A behavior fault stops target updates and leaves the PCA9685 at its last commanded pulse widths. A PCA9685 I2C failure also stops new commands, but the controller or servo can retain its last output. Use the independent physical motor stop for unexpected motion. A motor-power cut releases holding torque. No software watchdog, encoder feedback, current feedback, thermal feedback, or safety-rated stop controller is claimed.

## Bench commissioning sequence

1. Keep all four horns disconnected from the links. Open the motor stop. Verify12 V input, LED5 V, Pi3.3 V logic, and the regulated6 V servo output separately. Confirm the2200 µF capacitor polarity.
2. With servo V+ still disconnected, run i2cdetect -y 1. Confirm PCA9685 at0x40 and the mux at0x70. Check every PCA9685 signal lead and all five mux branches against wiring.csv.
3. Test the five sensors with .venv/bin/python -m luma.bench sensors --seconds 10. Cover one pedestal aperture at a time and confirm the reported port/name order.

Digital prototype · dimensions in mm · physical validation required | 21
4. Connect one unloaded servo and one3 A fused branch. With the stop in reach, run .venv/bin/python -m luma.bench servo --joint yaw --pulse-us 1500 --seconds 2 --confirm-unloaded, changing --joint for each channel. The command disables the other three PWM channels and removes the selected PWM pulse when the bounded check ends. Mark the resulting physical neutral.
5. Power off. Fit each straight metal arm to its indexed servo. Dry-fit its two printed radial slots and the opposite625/M5 support. Confirm free rotation, bearing alignment, smooth-shank contact at the inner race, and no bolt contact with the servo case.
6. Test the standard or DSI display and both LED rings. Verify that outer RGB is at20% or less and inner W is at192/255 or less. Measure LED, regulator, Pi, and enclosure temperatures during a30-minute run.
7. Verify that the physical stop removes voltage at the6 V star with the Pi unplugged. Verify BCM27 reports stop when either NC2 wire is removed. Reset only while the head is supported.
8. Enter measured neutral pulses and joint signs in config.json. Set calibrated=true only after every unloaded joint moves in the correct direction. Run hardware mode without --arm, then one supported6-second scene with --arm.
9. Check the complete limited motion for cable clearance, collision, stability, servo/regulator temperature, and loaded6 V droop. Reduce travel or redesign the counterbalance if any joint cannot sustain the pose.

## Evidence and limits

Host behavior and PWM-conversion tests run without hardware. The CAD uses the vendor's body envelope and the Adafruit board's published mounting coordinates. Physical servo fit, horn-hole fit, PCA9685 board revision, regulator cooling, electrical continuity, holding torque, optical range, and thermal behavior remain first-build checks. Budget figures are planning allowances, not quotations.

Digital prototype · dimensions in mm · physical validation required | 22

# Point-to-point wiring schedule

Use these connection names together with the electrical chapter. Physical Raspberry Pi header numbers and BCM GPIO numbers are explicitly distinguished. Disconnect the supplies while changing wiring. Nets starting with DSI_ apply only to the optional 4-inch DSI head and replace FACE_USB.

Net | From → to | Cable / connection detail
3V3_LOGIC | Raspberry Pi4: physical1 3V3 → Mux5626: VIN | STEMMAQT upstream red. All I2C pullups stay3.3V
GND_LOGIC | Raspberry Pi4: physical6 GND → Mux5626: GND

STEMMAQT upstream black. Connect DCSTARground also

I2C_SDA | Raspberry Pi4: physical3 BCM2 → Mux5626: SDA

STEMMAQT upstream blue. I2C bus1 at100kHz

I2C_SCL | Raspberry Pi4: physical5 BCM3 → Mux5626: SCL

STEMMAQT upstream yellow. I2C bus1 at100kHz

TOF_FRONT | Mux5626: port0 → VL53L1X front pedestal: STEMMAQT4pin
4conductor JSTSH. Address0x29 isolated on channel0; wall angle90deg
TOF_FRONT_LEFT | Mux5626: port1 → VL53L1X front-left pedestal: STEMMAQT4pin

4conductor JSTSH. Wall angle162deg

TOF_REAR_LEFT | Mux5626: port2 → VL53L1X rear-left pedestal: STEMMAQT4pin

4conductor JSTSH. Wall angle234deg

TOF_REAR_RIGHT | Mux5626: port3 → VL53L1X rear-right pedestal: STEMMAQT4pin

4conductor JSTSH. Wall angle306deg

TOF_FRONT_RIGHT | Mux5626: port4 → VL53L1X front-right pedestal: STEMMAQT4pin

4conductor JSTSH. Wall angle18deg; leave every optical aperture clear

PWM_VCC | Raspberry Pi4: physical1 3V3 → PCA9685: VCC

22AWG. Powers controller logic only; never powers a servo

PWM_GROUND | DCstar: GND → PCA9685: GND | 18AWG. Common reference to Pi sensor bus and all servo signal returns
PWM_SDA | Raspberry Pi4: physical3 BCM2 → PCA9685: SDA | 26AWG. Shared upstream I2C bus; address0x40
PWM_SCL | Raspberry Pi4: physical5 BCM3 → PCA9685: SCL

26AWG. Shared upstream I2C bus;50Hz PWM configured in software

PWM_ENABLE | DCstar: GND → PCA9685: /OE | 26AWG. Active-low output enable held low
RGB_DATA3V3 | Raspberry Pi4: physical19 BCM10 MOSI → 74AHCT125: DIP2 1A | 26AWG. Do not connect SPI clock to ring
RGB_DATA5V | 74AHCT125: DIP3 1Y → RGB ring quadrant1: DIN via330ohm

26AWG. Resistor at first ring input

RGB_CHAIN1 | RGB quadrant1: DOUT → RGB quadrant2: DIN

solder jumper. Connect common5V andGND at all quadrants

RGB_CHAIN2 | RGB quadrant2: DOUT → RGB quadrant3: DIN

solder jumper. Mechanical backing supports solder joints

Digital prototype · dimensions in mm · physical validation required | 23
Net | From → to | Cable / connection detail
RGB_CHAIN3 | RGB quadrant3: DOUT → RGB quadrant4: DIN | solder jumper. Do not connect lastDOUT back to firstDIN
WHITE_DATA3V3 | Raspberry Pi4: physical12 BCM18 PWM0 → 74AHCT125: DIP5 2A

26AWG. Disable onboard analog audio

WHITE_DATA5V | 74AHCT125: DIP6 2Y → 24RGBW inner ring: DIN via330ohm

26AWG. SeparateGRBW data stream

SHIFT_ENABLE | DCstar: GND → 74AHCT125: DIP1 /1OE andDIP4 /2OE

26AWG. Active outputs; tie both low

SHIFT_UNUSED | 5VLED: +5V → 74AHCT125: DIP10 /3OE andDIP13 /4OE

26AWG. Unused outputs disabled

SHIFT_UNUSED_INPUT | DCstar: GND → 74AHCT125: DIP9 3A andDIP12 4A

26AWG. UnusedDIP8 andDIP11 outputs unconnected

SHIFT_SUPPLY | 5VLED: +5V → 74AHCT125: DIP14 VCC

24AWG. 100nF betweenDIP14 andDIP7

SHIFT_GROUND | DCstar: GND → 74AHCT125: DIP7 GND

24AWG. Shared reference toPi andboth rings

PI_GROUND | Raspberry Pi4: physical9 GND → DCstar: GND

22AWG. Common ground only; never tie5VLED toPi5V

PI_POWER | Pi official supply: USB-C5.1V3A → Raspberry Pi4: USB-Cpower

factory cable. Independent from motor12V

FACE_USB | Raspberry Pi4: USB-Aport1 → DisplaySKU28514: USB-C

data cable. Do not add a second5V power feed

AUDIO_USB | Raspberry Pi4: USB-Aport3 → USB speaker3369: USB

captive cable. LimitUSB total current toPi specification

DC_INPUT | MeanWellGST220A12: R7B+12V → Main15Afuse: input

16AWG. Use correctparallel contacts from supply drawing

DC_MAIN | Main15Afuse: output → DC12Vdistribution: +12V
16AWG. Supply remains outside printed enclosure
DC_RETURN | MeanWellGST220A12: R7Breturn → DCstar: GND
16AWG. All high-current returns star here
STOP_COIL_FEED | DC12Vdistribution: +12V → 0.5Afuse: input

22AWG. Coil branch

STOP_NC1 | 0.5Afuse: output → StopNC1: COM | 22AWG. NoPiGPIO in this branch
STOP_COIL_PLUS | StopNC1: NC → Relay: coilpositive | 22AWG. Diodecathode stripe here
STOP_COIL_MINUS | Relay: coilnegative → DCstar: GND | 22AWG. Diodeanode here
MOTOR_RELAY_IN | DC12Vdistribution: +12V → Relay: COM highcurrent | 16AWG. NOcontact>=15A12VDC
MOTOR_RELAY_OUT | Relay: NO highcurrent → Servo regulator7.5Afuse: input

16AWG. Stop removes regulator input and all motor V+ independent of software

SERVO_REG_INPUT | Servo regulator7.5Afuse: output → PololuD42V110F6: VIN

16AWG. 12V nominal input; mount with airflow

Digital prototype · dimensions in mm · physical validation required | 24
Net | From → to | Cable / connection detail
SERVO_6V | PololuD42V110F6: VOUT6V → Servo4way fusedstar: input | 16AWG. Verify6V and polarity before connecting any servo
SERVO_BULK | Servo6Vstar: +6V/GND → 2200uF10Vcapacitor: +/-

short18AWG. Observe polarity and place near star distribution

SERVO_POWER1 | Servo3Afuse1: output → YawDS3218MG: V+

18AWG. Separate6V feed; do not carry power through PCA9685 traces

SERVO_POWER2 | Servo3Afuse2: output → ShoulderDS3218MG: V+

18AWG. Separate6V feed

SERVO_POWER3 | Servo3Afuse3: output → ElbowDS3218MG: V+

18AWG. Separate6V feed

SERVO_POWER4 | Servo3Afuse4: output → WristDS3218MG: V+

18AWG. Separate6V feed

SERVO_GROUNDS | AllfourDS3218MG: GND → DCstar: GND
18AWG. One power return per servo; common with PCA9685 logic ground
SERVO_PWM1 | PCA9685: channel0 signal → YawDS3218MG: PWM

26AWG. 500-2500us range;1500us nominal neutral; signal and ground only at controller

SERVO_PWM2 | PCA9685: channel1 signal → ShoulderDS3218MG: PWM

26AWG. Confirm direction before fitting loaded horn

SERVO_PWM3 | PCA9685: channel2 signal → ElbowDS3218MG: PWM

26AWG. Confirm direction before fitting loaded horn

SERVO_PWM4 | PCA9685: channel3 signal → WristDS3218MG: PWM

26AWG. Confirm direction before fitting loaded horn

STOP_SENSE | Raspberry Pi4: physical13 BCM27 → StopNC2: COM

26AWG. External10kohm toPi3.3V

STOP_SENSE_RETURN | StopNC2: NC → Raspberry Pi4: physical14 GND

26AWG. Opencontact orbrokenwire readsstop

BUCK_INPUT | DC12Vdistribution: +12V via2Afuse → PololuD24V50F5: VIN

22AWG. ENleftunconnected

BUCK_GND | PololuD24V50F5: GND → DCstar: GND
22AWG. Shortreturn
LED_FUSED | PololuD24V50F5: VOUT5V → 3Afuse: input

22AWG. Verify5VbeforeconnectingLEDs

LED_RGB_POWER | 3Afuse: output5V → Outer60RGB: 5V atoppositequadrants
22AWG. 1000uF10Vcap at ring
LED_WHITE_POWER | 3Afuse: output5V → Inner24RGBW: 5V
22AWG. 1000uF10Vcap at ring
LED_RETURNS | Bothrings: GND → DCstar: GND | 22AWG. KeepLEDreturnseparatefromI2Creturnuntilstar
DSI_DATA | Raspberry Pi4: DSI connector → 4inch DSI LCD (C): 15-pin DSI FPC | 15-pin1.0mm FFC800mm type A. Optional head only;replaces FACE_USB;route through both arm cable ports with a service loop at each joint
DSI_POWER | Raspberry Pi4: physical4 5V → 4inch DSI LCD (C): HP2.0 4-pin 5V | 22AWG. Optional head only;display draws from the Pi supply in place of the USB display

Digital prototype · dimensions in mm · physical validation required | 25
Net | From → to | Cable / connection detail
DSI_GROUND | Raspberry Pi4: physical39 GND → 4inch DSI LCD (C): HP2.0 4-pin GND | 22AWG. Optional head only;SDA and SCL contacts of this plug stay empty;touch and backlight use the DSI connector I2C bus10

Digital prototype · dimensions in mm · physical validation required | 26

# LUMA Pi4 controller and face firmware

The project includes a deterministic simulator and Raspberry Pi adapters for five pedestal ranging sensors, four Miuzei DS3218MG servos through a PCA9685, two independent LED rings, USB face display and local spoken Hi. The simulation needs Python3.11 or later.

cd software
python -m luma.app --scene wink
python -m luma.app --scene hi
python -m luma.app --scene happy
python -m unittest discover -s tests -v

Simulation prints timestamped pose/light/face events as JSON. It advances deterministically without sleeping. --seconds sets duration. Scenes last6seconds, then return to idle. The three promotional scenes remain within the initial CAD travel envelope; they are repeatable face/motion scripts and do not require a cloud service.

## Raspberry Pi installation

Use Raspberry Pi OS Bookworm64bit on Pi4. The following setup commands affect only a Pi used for this project; do not execute them on the development Windows computer.

sudo apt update
sudo apt install python3-venv python3-pip python3-dev i2c-tools espeak-ng alsa-utils
sudo raspi-config

In Interface Options enable I2C and SPI. In /boot/firmware/config.txt, confirm dtparam=i2c_arm=on, dtparam=i2c_arm_baudrate=100000, and dtparam=spi=on. Set dtparam=audio=off because BCM18's PWM peripheral drives theRGBW ring and analog audio conflicts. USB audio is separate. Reboot after these settings.

cd software
python3 -m venv .venv
.venv/bin/pip install -e '.[hardware]' ls -l /dev/serial/by-id/
aplay -l

Enter the actual display /dev/serial/by-id/ path in config.json. The PCA9685 is I2C address64 (0x40), with yaw/shoulder/elbow/wrist on channels0/1/2/3. Select the USB speaker as the ALSA output or set audio_device to the identifier from aplay -L. The standard display and speaker share Pi4 USB power; use a powered hub if measurement requires it. Motors and LEDs never take power from Pi USB or GPIO.

Before connecting motor power, test the sensor chain and display independently. These commands do not instantiate the PCA9685 or LED drivers and do not require calibrated joints:

.venv/bin/python -m luma.bench sensors --seconds 10
.venv/bin/python -m luma.bench display --port /dev/serial/by-id/YOUR_DISPLAY_DEVICE --scene all
--seconds 10

The sensor check reports millimeters, age and mux channel in front/front-left/rear-left/rear-right/front-right order. Present a matte target at each pedestal aperture. near means a valid value below100mm: communication can pass, but armed motion would fault. The display check cycles idle/wink/Hi/happy and checks firmware replies. Inspect the pixels yourself. Exit status0 is pass,1 fail and130 interrupted. I2C normally needs membership in the i2c group; USB serial normally needs dialout.

Center only one disconnected, unloaded servo at a time. Keep its straight horn off the arm and keep the physical stop in reach. The command is capped at10seconds, disables the other three PCA9685 channels, and removes the selected PWM pulse when it exits:

.venv/bin/python -m luma.bench servo --joint yaw --pulse-us 1500 --seconds 2 --confirm-unloaded

Repeat with shoulder, elbow and wrist. Power off before installing each horn. The DS3218 datasheet gives500-2500µs over270° with1500µs nominal neutral. Record the actual mechanical neutral in neutral_pulse_us; do not use this command on a loaded joint.

Digital prototype · dimensions in mm · physical validation required | 27

The PWM-backed NeoPixel library normally requires root on Pi4, so the full hardware command uses the virtual environment interpreter with sudo. Leave calibrated=false while wiring/testing. Hardware mode without --arm requires PCA9685 communication but leaves all four PWM outputs disabled; the separate6V motor rail can remain off.

sudo .venv/bin/python -m luma.app --hardware --scene hi --seconds 6

Complete the commissioning procedure in ../electronics/architecture.md, including unloaded neutral indexing, polarity/sign checks, physical stop tests and five valid pedestal ranges. Only then set calibrated=true. Support the arm in its indexed pose before every armed start; software cannot read its physical angles:

sudo .venv/bin/python -m luma.app --hardware --arm --scene happy --seconds 6

Any fault latches for that process. It stops new targets and leaves the PCA9685 at the last pulse widths. Inspect the reason, support the arm, remove the cause and restart explicitly. PCA9685 health proves I2C communication only, not servo movement or position. The physical motor stop removes6V holding power. There is no unattended boot or auto-arm service.

## Display firmware

display_firmware/ targets ESP32-S3-Touch-LCD-1.85 SKU28514 only. It uses USB serial115200, an ST77916 QSPI controller on CS21/SCK40/D046/D145/D242/D341, and a TCA9554 at0x20 over SDA11/SCL10 for LCD resetEXIO2/P1. Backlight is GPIO5. This pin mapping is from the Waveshare board documentation (https://docs.waveshare.com/ESP32-S3-Touch-LCD-1.85) and schematic. Firmware reads panel register0x04 and chooses one of the exact two vendor initialization tables: ID00-7F-7F-7F or00-02-7F-7F. Unknown IDs produce an error and do not advertise READY. Register command/data/delay values were converted from the vendor's April2025 demo to Arduino_GFX (https://github.com/moononournation/Arduino_GFX/tree/v1.6.5) operations. A successful compile does not prove physical display operation; verify the purchased panel on the bench.

Install PlatformIO and build/flash the connected board:

python -m pip install platformio
cd display_firmware
python -m platformio run
python -m platformio run --target upload --upload-port YOUR_SERIAL_PORT
python -m platformio device monitor --port YOUR_SERIAL_PORT --baud 115200

Commands are newline-delimited ASCII. PING replies PONG. FACE idle, FACE wink, FACE hi, FACE happy, and FACE fault reply OK <name>. Startup announces READY LUMA1. Invalid or overlong commands reply ERR. After1.5seconds without a host command/heartbeat the display shows WAITING. The host sends heartbeat every250ms and latches a motion hold if replies stop. No touch/audio/SD/battery functions are enabled on the display board; speech is generated on the Pi and played by the USB speaker.

## Optional 4-inch DSI head (Pi-rendered face)

Instead of the ESP32 face board, LUMA can use a Waveshare 4inch DSI LCD (C) — a round720x720 panel wired directly to the Pi's DSI port. There is no coprocessor for this head: the Pi itself renders the face every frame with luma/face.py, which reproduces paint() from display_firmware/src/main.cpp in Python (same colors, same shapes, same scene timing) scaled from the firmware's360x360 canvas up to the panel's720x720 resolution.

Select this head by setting "display_kind": "dsi" in config.json (leave display_port alone; it is ignored for this kind). Install the extra dependency alongside the existing hardware group:

.venv/bin/pip install -e '.[hardware,dsi]'

Add these lines to /boot/firmware/config.txt for the Waveshare4inch DSI LCD(C):

dtoverlay=WS_xinchDSI_Screen,SCREEN_type=10,I2C_bus=10
dtoverlay=WS_xinchDSI_Touch,I2C_bus=10

Both overlays are the vendor's documented setup; LUMA's software never reads touch events — the lamp has no touch-driven behavior. If the picture is upside down for the mounted orientation (connectors at the bottom), rotate it with the vendor's documented display_lcd_rotate/Wayland rotation setting rather than in LUMA.

Digital prototype · dimensions in mm · physical validation required | 28

Running outside a desktop session (the normal case for an unattended lamp) needs pygame's KMS/DRM backend. sudo drops environment variables, so pass the driver through env:

sudo env SDL_VIDEODRIVER=kmsdrm .venv/bin/python -m luma.app --hardware --scene hi --seconds 6

Bench-check the head on its own, the same way as the USB face board:

.venv/bin/python -m luma.bench display --kind dsi --scene all --seconds 10

--port is not required (and is ignored) when --kind dsi; it stays required for the default --kind usb_serial. There is no serial heartbeat to a coprocessor for this head, so Hardware/bench.display's notion of "heartbeat" becomes "a frame was drawn within the last1.5seconds" — DsiDisplay.update() returns that boolean the same way Display.update() returns the USB PONG heartbeat, so the rest of the control/fault-latching logic in luma/control.py is unaffected by which head is attached.

## Source/verification notes

luma/servo_pwm.py uses the maintained Adafruit CircuitPython PCA9685 library at50Hz. It converts calibrated angles through the DS3218's documented500-2500µs/270° range, starts with all four outputs disabled, and checks controller registers over I2C. The bounded bench path enables one unloaded channel only. Tests cover the duty conversion, channel isolation, config validation, scene limits, five renamed sensor inputs and fault behavior. Hardware paths have not been exercised on a physical Pi/arm.

The pinned firmware toolchain is self-contained in platformio.ini; downloaded SDK/toolchain caches are development artifacts and do not need redistribution. Python hardware dependency versions are bounded for installation flexibility, not a physical acceptance-tested lockfile. Record actual installed versions with pip freeze when commissioning the Pi.

Digital prototype · dimensions in mm · physical validation required | 29

# First-build verification and maintenance

## Verify before enclosing

Power and exercise the display, rings and each pedestal sensor on the bench. Confirm that the large ring shows the intended colors, the small ring uses only its white channel during lamp operation, and every wall direction is associated with its labeled multiplexer port.

Connect one unloaded DS3218MG at a time to its fused6V feed and PCA9685 channel. Use the bounded one-channel command in the software guide to center it at1500µs, then remove power before attaching the horn. Save each measured neutral pulse and direction with the assembled unit. PWM servos have no readable shaft position.

## Mechanical acceptance record

Check | Acceptance and record
Printed interfaces | Actual purchased boards and horns seat without forced deflection; record component revision.
Fasteners | Required washers/nuts present, rotating surfaces free and wires not under screw heads.
Bearings and joints | Free motion when unpowered; no binding, visible cracks or loose axial play.
Cable routing | Slack remains throughout allowed travel; no pinched insulation or tight connector bends.
Stability | Base secured as specified; verify measured mass and center of gravity at the maximum allowed reach.
Head mass | Weigh the completed head and replace assumed mass in the torque calculation.
Horns | Metal horns secured with the servo's correct center screw; no printed spline substitutes.
Pitch idlers | Three625 bearings square in their pockets; M5 smooth shanks load only inner races; captive nuts seated; no axial bind or play.
Pedestal sensors | Five boards on four screws each; component face outward; apertures open; one strain-relieved STEMMA QT cable per board.
Enclosed links | DS3218 case seated in the41.2 ×20.7mm pocket; halves meet without crushing it; harness has slack; horn, idler and servo tab clear the commissioned travel.
Optional DSI head | Carrier pads bear on all four display bosses; face ring bears on the foam rim only, never on the glass; FFC bend radius above 10 mm at every turn; picture stable at full backlight for 30 minutes with the arm closed.

## Electrical and motion acceptance

Start with the arm supported and a single joint enabled at reduced speed. Move a few degrees about the calibrated neutral position, verify the sign of rotation, then return to neutral. Repeat for each joint before a coordinated expression. A wrong sign or zero offset must be corrected before enlarging the motion range.

Confirm that the hardware motor-power disconnect removes the regulated6V rail independently of software. Support the head when testing a power cut. Verify the software fault response for a missing sensor, invalid range, lost PCA9685 communication and lost display connection. A live PCA9685 does not prove that a servo moved.

Run the normal white-light and RGB settings with the head assembled. Record temperatures at5,15 and30 minutes at the LED support, screen,6V regulator and most heavily loaded servo. The DS3218 gives no telemetry, so measure accessible surfaces directly. Use45°C on a printed enclosure surface as a conservative investigation threshold for the first PETG build, not as a product certification.

Digital prototype · dimensions in mm · physical validation required | 30

Verify front, front-left, rear-left, rear-right and front-right with a matte target at several distances. Record ranges and reject invalid readings rather than treating them as open space. Check for wall-edge reflections. These five horizontal cones do not cover every direction or arm pinch point.

## Verification worksheet

Measurement | First-build result
Build date / builder | __________________________________
Printer and filament | __________________________________
Component revisions | __________________________________
Completed head mass | __________________________________
Base / ballast mass | __________________________________
Motor supply at motion peak | __________________________________
Regulated servo rail / PCA9685 check | __________________________________
LED supply at normal brightness | __________________________________
Pi undervoltage check | __________________________________
Maximum observed enclosure / servo / regulator temperature | __________________________________

Mechanical travel limits and neutral pulse
widths

__________________________________

Sensor directions and valid range test | __________________________________
Hardware power-cut test | __________________________________

## Care and service

Inspect the horn screws, bearing mounts and cable strain relief after the first hour of motion and again after the first week. Stop using a printed part if a layer crack, whitening around a fastener or increasing joint play appears. Correct the cause before replacing the part.

Clean the diffuser with a soft damp cloth. Keep solvents away from printed surfaces and the display. Dust near a time-of-flight aperture can change measurements; remove it without pushing debris onto the optical package.

For service, shut down the Pi, disconnect the low-voltage supplies and support the arm before opening a joint or loosening the head. Store the final calibration, BOM revision and any dimensional changes with the project so the next printed replacement matches the machine.

Digital prototype · dimensions in mm · physical validation required | 31

# Finished design and promotional films

The promotional films show the LUMA digital prototype built from the supplied CAD geometry. The lighting, camera exposure, screen graphics and sound are presentation choices; the films do not establish the physical lamp's brightness, motor sound or production finish.

Finished LUMA digital prototype, rendered from the project geometry.

## The three films

Film | Included file | Action
The wink | media/videos/01_wink.mp4 | A brief one-eye wink with a coordinated head gesture and colored halo.
Hi, there | media/videos/02_hi.mp4 | A friendly face greeting, arm gesture and an audible “Hi!”
Happy to see you | media/videos/03_happy.mp4 | Cheerful eyes and a small happy movement, with warm halo color.

Open START_HERE.html in a browser after extracting the archive to play all three clips. The videos are also individual files for editing or presentation use. The project includes editable animation sources under media/sources/.

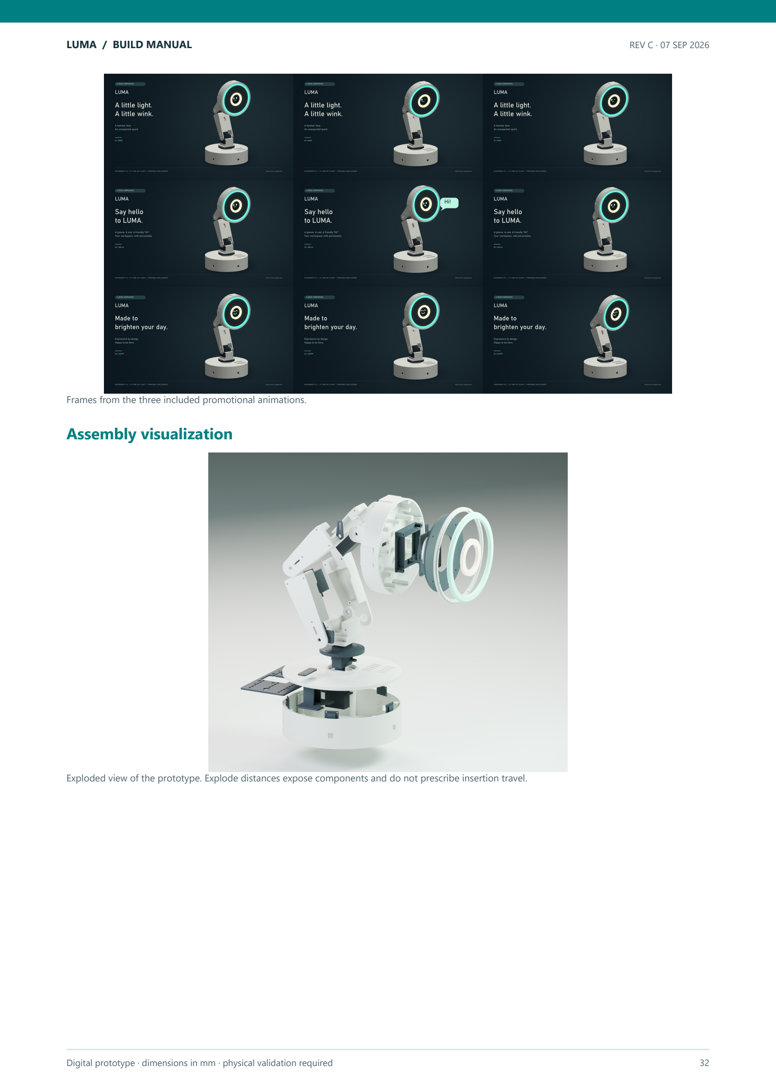
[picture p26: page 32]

Digital prototype · dimensions in mm · physical validation required | 32

Frames from the three included promotional animations.

## Assembly visualization

Exploded view of the prototype. Explode distances expose components and do not prescribe insertion travel.

Digital prototype · dimensions in mm · physical validation required | 33

Optional 4-inch DSI head, rendered from cad/assembly_dsi.json with the same enclosed arm and base.

The engineering sheets at the back of the manual are the dimensional references. The rendered images explain appearance and assembly relationships; use the numbered assembly sequence for fasteners, wiring and the optical stack.

Digital prototype · dimensions in mm · physical validation required | 34

# Digital release checks

The included validation files record what was checked on the development computer. They should travel with the source and manual when the project is revised. Passing these checks does not replace the first-build measurements in the preceding chapter.

## Executed host software checks

The controller, bench diagnostic, PWM and face-renderer suite passed38 tests. It exercises all three expressions, angle/slew limits, the five pedestal channel names and order, stale/invalid/near ranges, latched faults, stop polarity, lost display or PCA9685 communication, and the one-shot greeting.

Additional tests verify the500-2500µs/270° conversion, a known PCA9685 duty value, one-channel commissioning with the other channels disabled, neutral calibration gating, and white-channel limits. Face tests render the optional DSI output off-screen and check expression/fault pixels. The simulator and tests activate no physical hardware.

## Meshes and assembly

cad/validation.json records exporter mesh properties. validation/assembly_check.json covers27 printable types and reports zero printed-part overlaps above0.5mm³ in the standard24-instance and DSI21-instance assemblies. cad/purchased_fit.json reports no intersection for four DS3218MG case/tab envelopes, five Adafruit3967 pedestal-board envelopes, and either display envelope.

The intersection check is limited to the indexed pose. It excludes real horns/splines,625 bearings, screws and moving cables. It cannot prove the supplied straight-horn hole pattern, physical sensor alignment, or a collision-free moving envelope. The4-inch DSI connector position remains estimated from a vendor photograph.

## PDF and media

validation/final_report.json records the final PDF page/bookmark count, text bounds and full decoding of each promotional MP4. The verification script also generates a contact sheet of the manual for visual review. Video metadata and frame counts verify the encoded files; the animation is a visualization of the digital design. The optional head is rendered as a still only; the films show the standard head.

## Display firmware build status

The firmware source includes the exact-board pin mapping and the vendor's two panel initialization variants with attribution. Its cross-compilation was not completed in this environment: the required PlatformIO compiler download did not finish, and an alternate download was truncated. No firmware binary or successful cross-compile is claimed. Run the supplied PlatformIO build on a connected development computer before flashing, and test the purchased display on the bench. The optional DSI head does not use this firmware.

## Physical work still required

Actual Raspberry Pi GPIO/I2C/USB operation, PCA9685 output,6V regulator cooling, horn/idler fit, servo holding ability, electrical continuity, stop behavior, sensor optics, light diffusion, stability and enclosed temperatures have not been tested on a physical unit. The DS3218 servos expose no position/current/temperature telemetry. The800mm optional DSI cable is also untested. Record all first-build results on the worksheet.

Digital prototype · dimensions in mm · physical validation required | 35

# Component source register

Vendor information checked for this digital release. Order by exact part number and verify the revision supplied. Prices in the BOM are budgeting references, not quotations.

S01 · Autonomous Lamp — appearance reference (https://www.autonomous.ai/lamp)
Inspiration for an articulated desk companion; no commercial-lamp geometry reused.

S02 · Raspberry Pi 4 Model B (https://www.raspberrypi.com/products/raspberry-pi-4-model-b/)
Master computer and USB-C supply selection.

S03 · Waveshare ESP32-S3-Touch-LCD-1.85 documentation (https://docs.waveshare.com/ESP32-S3-Touch-LCD-1.85)
Exact integrated LCD board, display resolution, interface and vendor firmware reference.

S04 · Adafruit VL53L1X STEMMA QT — product 3967 (https://www.adafruit.com/product/3967)
Five sensor boards, nominal dimensions and default I2C address.

S05 · Adafruit VL53L1X guide (https://learn.adafruit.com/adafruit-vl53l1x)
Sensor software and wiring reference.

S06 · Adafruit RGBW 24-pixel ring — product 2862 (https://www.adafruit.com/product/2862)
Inner white-light ring, RGBW format and mechanical envelope.

S07 · Adafruit 60-pixel RGB ring quarter — product 1768 (https://www.adafruit.com/product/1768) Four supported arcs form the outer RGB halo.

S08 · Adafruit NeoPixel rings guide (https://learn.adafruit.com/adafruit-neopixel-uberguide/neopixel-rings)
Ring diameter reference.

S09 · Miuzei DS3218 6V 20kg servo datasheet (https://images-na.ssl-images-amazon.com/images/I/81Lbgu%2BnG6L.pdf)
Inventory servo body dimensions, voltage, current, torque, PWM pulse range and 270-degree option.

S10 · Adafruit PCA9685 16-channel PWM/servo driver guide (https://learn.adafruit.com/16-channel-pwm-servo-driver)
User-selected PCA9685 control topology, separate VCC/V+ power and Python driver.

S11 · Pololu D42V110F6 6V 11A regulator (https://www.pololu.com/product/5673)
Regulated 6V servo rail, current capability, dimensions and mounting holes.

S12 · Adafruit PCA9548 STEMMA QT multiplexer — product 5626 (https://www.adafruit.com/product/5626) Independent channels for five sensors with identical addresses.

S13 · Waveshare 4inch DSI LCD (C) — round 720×720 DSI display (https://www.waveshare.com/4inch-dsi-lcd-c.htm)
Optional head display: outline, case thickness, M4 boss pattern and PCB envelope from the vendor drawing and STEP model; config.txt overlays from the vendor wiki.

S14 · Adafruit VL53L1X PCB source (https://github.com/adafruit/Adafruit-VL53L1X-PCB)
Exact25.40×17.78mm board outline and four2.5mm holes on20.32×12.70mm centers.

LUMA / ENGINEERING DRAWINGS

# Finished assembly / indexed neutral pose

Assembled geometry from the same STL files supplied for printing. Purchased parts are simplified envelopes.

UNITS mm · THIRD-ANGLE PART VIEWS · NUMERICAL DIMENSIONS CONTROL

Views fitted to sheet. Do not measure this PDF. Digital prototype; check physical fit before batch printing.

G01

REV C | 07 SEP 2026 | A3

FRONT / LCD FACING VIEW

216.00

420.74

RIGHT SIDE / NEUTRAL POSE

216.00

420.74

TOP / FOOTPRINT

216.00

216.00

Four axes: yaw about Z; shoulder, elbow and wrist about local X. Datum is the base underside at Z=0.
Nominal linkage pitches: shoulder–elbow 140 mm; elbow–wrist 120 mm. The illustrated height is a pose dimension, not a motion envelope. Neutral: shoulder link 115° above horizontal; forearm 45° above horizontal; face directed toward +Y. Follow indexed calibration in the manual.
Five Adafruit3967 boards mount inside the pedestal wall. Four DS3218MG servos use driven straight horns and opposite625 supports at pitch joints. Do not infer screw lengths from the illustration. Fasteners and service loops are specified in the assembly chapter.

# Head / layered assembly study

Exploded positions expose the optical parts; displacements are illustrative and are not insertion paths.

G02

EXPLODED HEAD / MODEL-DERIVED VIEW

### LAYER REFERENCES

01 Head tilt fork

02 head driven horn spacer

03 Head Shell

04 Outer Bezel

05 Face Center

06 White Carrier

07 Lcd Cradle

08 Lcd Retainer

09 Outer Diffuser

10 Inner Diffuser

11 Purchased LCD envelope

Central LCD board is behind the inner white ring. Keep all optical components at their documented axial heights.
Use natural PETG for both light diffusers and opaque PETG for the optical baffle. Leave LCD glass clear; all ToF apertures are in the pedestal. The four outer ring PCB quarters require continuous mechanical support. Solder joints are electrical connections only.
Refer to the head assembly chapter for screw order, spacers, wire relief and board retention. Purchased LEDs are not printable parts.

# Optional 4-inch DSI head / indexed neutral pose

Same sensor-equipped pedestal, arm links and fork as G01. Head shell, carrier and face ring are the optional parts; the display envelope is measured from the vendor STEP.

G03

FRONT / LCD FACING VIEW

216.00

420.74

RIGHT SIDE / NEUTRAL POSE

216.00

420.74

EXPLODED DSI HEAD

Waveshare 4inch DSI LCD (C): Ø126 case, 6 mm thick, four M4 bosses on a 75 × 75 pattern. Rim front at head Z35.5; carrier plate Z20.5–23.5 with pads to the boss ends at Z25.5.
Face ring opening Ø108 chamfered to Ø116 leaves a 3 mm black rim around the Ø101.5 active area. Outer60-RGB halo, bezel, diffuser and fork are shared with the standard head.
No inner white ring on this head: the halo provides capped white output. Revision C has no head-mounted sensors or brow bracket.
Cables: 15-pin DSI FFC plus 5 V/GND leave through the 26 × 8 slot in the shell floor and fork plate, then run inside the enclosed links through their wall ports.

# Electrical connections / system wiring

Follow the point-to-point wiring schedule for connector pins, polarity and conductor ratings.

E01

# LUMA / Electrical connections

Revision C · Raspberry Pi 4 master · four PWM servos · five pedestal-wall ranging sensors

## Raspberry Pi 4

USB1: round LCD coprocessor

I2C0x40: PCA9685 servo PWM

USB3: local Hi speech speaker

I2C0x70: five-channel sensor mux

RGB: BCM10 / SPI MOSI

White: BCM18 / PWM

Stop sense: BCM27 + 10k pullup

## Waveshare ESP32-S3-Touch-LCD-1.85

SKU28514 · 360×360 TFT · USB serial face commands

## User-selected PCA9685 PWM controller

0x40 · 50Hz · channels0–3 · 3.3V logic only

## Four inventory Miuzei DS3218MG servos

Yaw / shoulder / elbow / wrist · separate fused6V feeds

## Adafruit3369 USB speaker / espeak-ng

## Adafruit5626 PCA9548 mux · 0x70

TCA9548A-compatible · 3.3V upstream logic

## Five Adafruit3967 VL53L1X · 0x29 each

Ports0–4: front / front-left / rear-left

rear-right / front-right · all inside pedestal wall

## 74AHCT125 / two 3.3V → 5V channels

DIP2→3 RGB · DIP5→6 white · 330Ω each output

VCC5V on14 · GND7 · enable1 and4 to GND

## Two independent light rings

Outer60RGB ≤20% · inner24RGBW: RGB0 / W≤192

1000µF across each ring supply · last outer DOUT open

## Two external supplies

Official Pi5.1V / 3A → Pi USB-C

Mean Well12V / 15A → DC only

## 12V distribution / 15A main fuse

Relay → 7.5A fuse → Pololu6V/11A → four3A feeds

Separate2A fuse → Pololu buck5V → 3A fuse → LEDs

## Latching physical motor stop / two NC

NC1 opens relay coil12V · diode across coil

NC2 grounds BCM27 normally · open = STOP

Read wiring.csv for exact connections, fuses, DIP pins and cable notes.

All DC grounds meet at one star point. Never join Pi5V and LED5V. Do not carry servo power through PCA9685 traces.

Motor stop cuts6V power: support the arm. PWM confirms no shaft position; five narrow ToF cones are not a safety perimeter.

Power wires shown in amber; signal routes in blue. Schematic overview: routing lengths and connector positions are not to scale.

# Steel ballast plate / fabrication drawing

## MATERIAL + INTERFACES

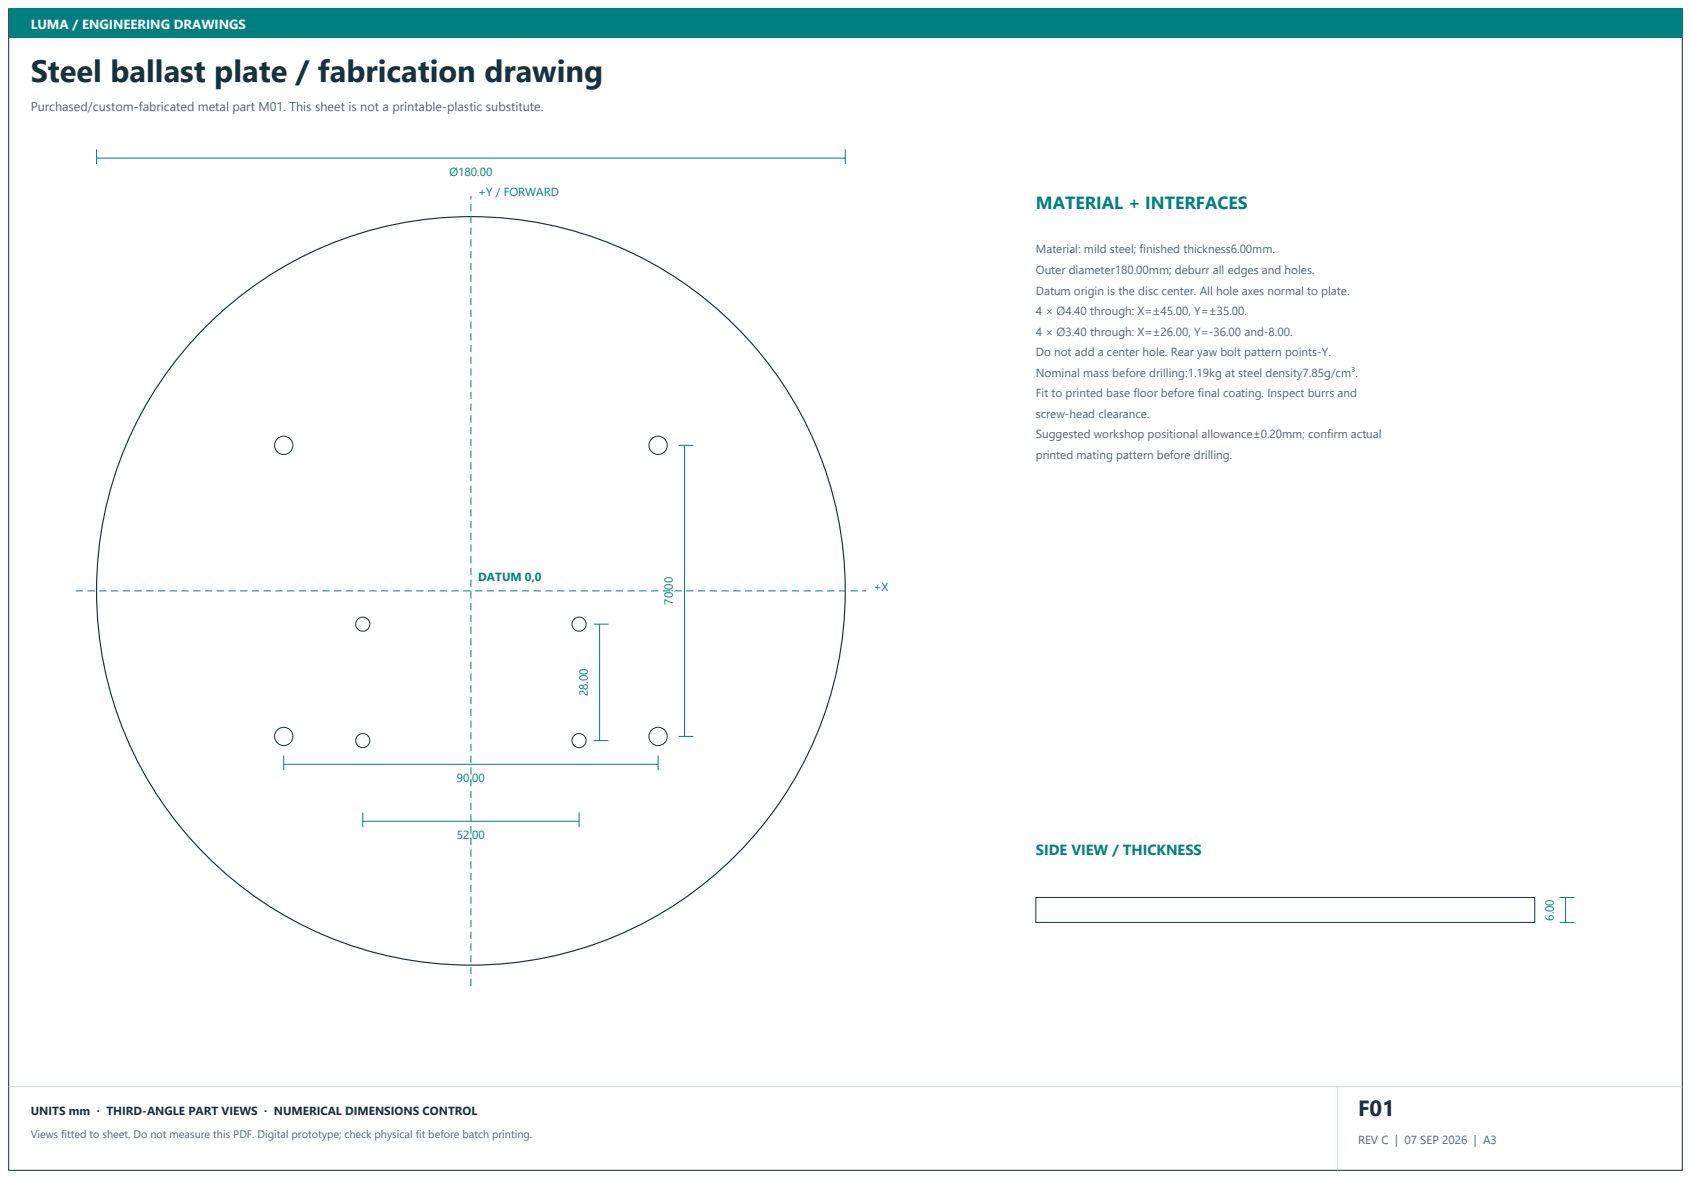
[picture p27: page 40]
DATUM 0,0; +Y / FORWARD

Purchased/custom-fabricated metal part M01. This sheet is not a printable-plastic substitute.

Material: mild steel; finished thickness6.00mm.
Outer diameter180.00mm; deburr all edges and holes.
Datum origin is the disc center. All hole axes normal to plate.
4 × Ø4.40 through: X=±45.00, Y=±35.00.
4 × Ø3.40 through: X=±26.00, Y=-36.00 and-8.00.
Do not add a center hole. Rear yaw bolt pattern points-Y.
Nominal mass before drilling:1.19kg at steel density7.85g/cm³.

Fit to printed base floor before final coating. Inspect burrs and
screw-head clearance.
Suggested workshop positional allowance±0.20mm; confirm actual
printed mating pattern before drilling.

SIDE VIEW / THICKNESS

# Weighted base enclosure with five internal ToF mounts

base_tub.stl | PRINT QUANTITY 1 | PETG

P01

TOP / XY

216.00

216.00
X

Y

0,0

FRONT / XZ

216.00

56.00

RIGHT / YZ

216.00

56.00

ISOMETRIC / REFERENCE

Interfaces: 216 diameter; 56 high; 3 floor; 3.5 wall; five sensor apertures and 20 internal bosses.
Fasteners / retention: 6 M3x12 lid screws; 4 M4 ballast retainers; 20 M2.5x6 sensor screws.
Print orientation: floor down. Layers 0.2 mm; 4 walls; 25% infill baseline.
Feature locations: M4 clearance4.4 at (+/-45,+/-35). Yaw bolts3.4 at (+/-26,-36) and (+/-26,-8). Six lid pilots2.8 at radius99, angles42/66/126/198/258/342deg. Five 10x10 wall apertures at18/90/162/234/306deg, Z25. Each board has four2.1 blind pilots on20.32x12.70 at tangent radius99. Rear ports occupy270/282deg.
General fit: inspect and deburr holes; check the fit coupon and actual hardware. No unlisted machining tolerances are implied.

# Vented base lid and yaw bearing seat

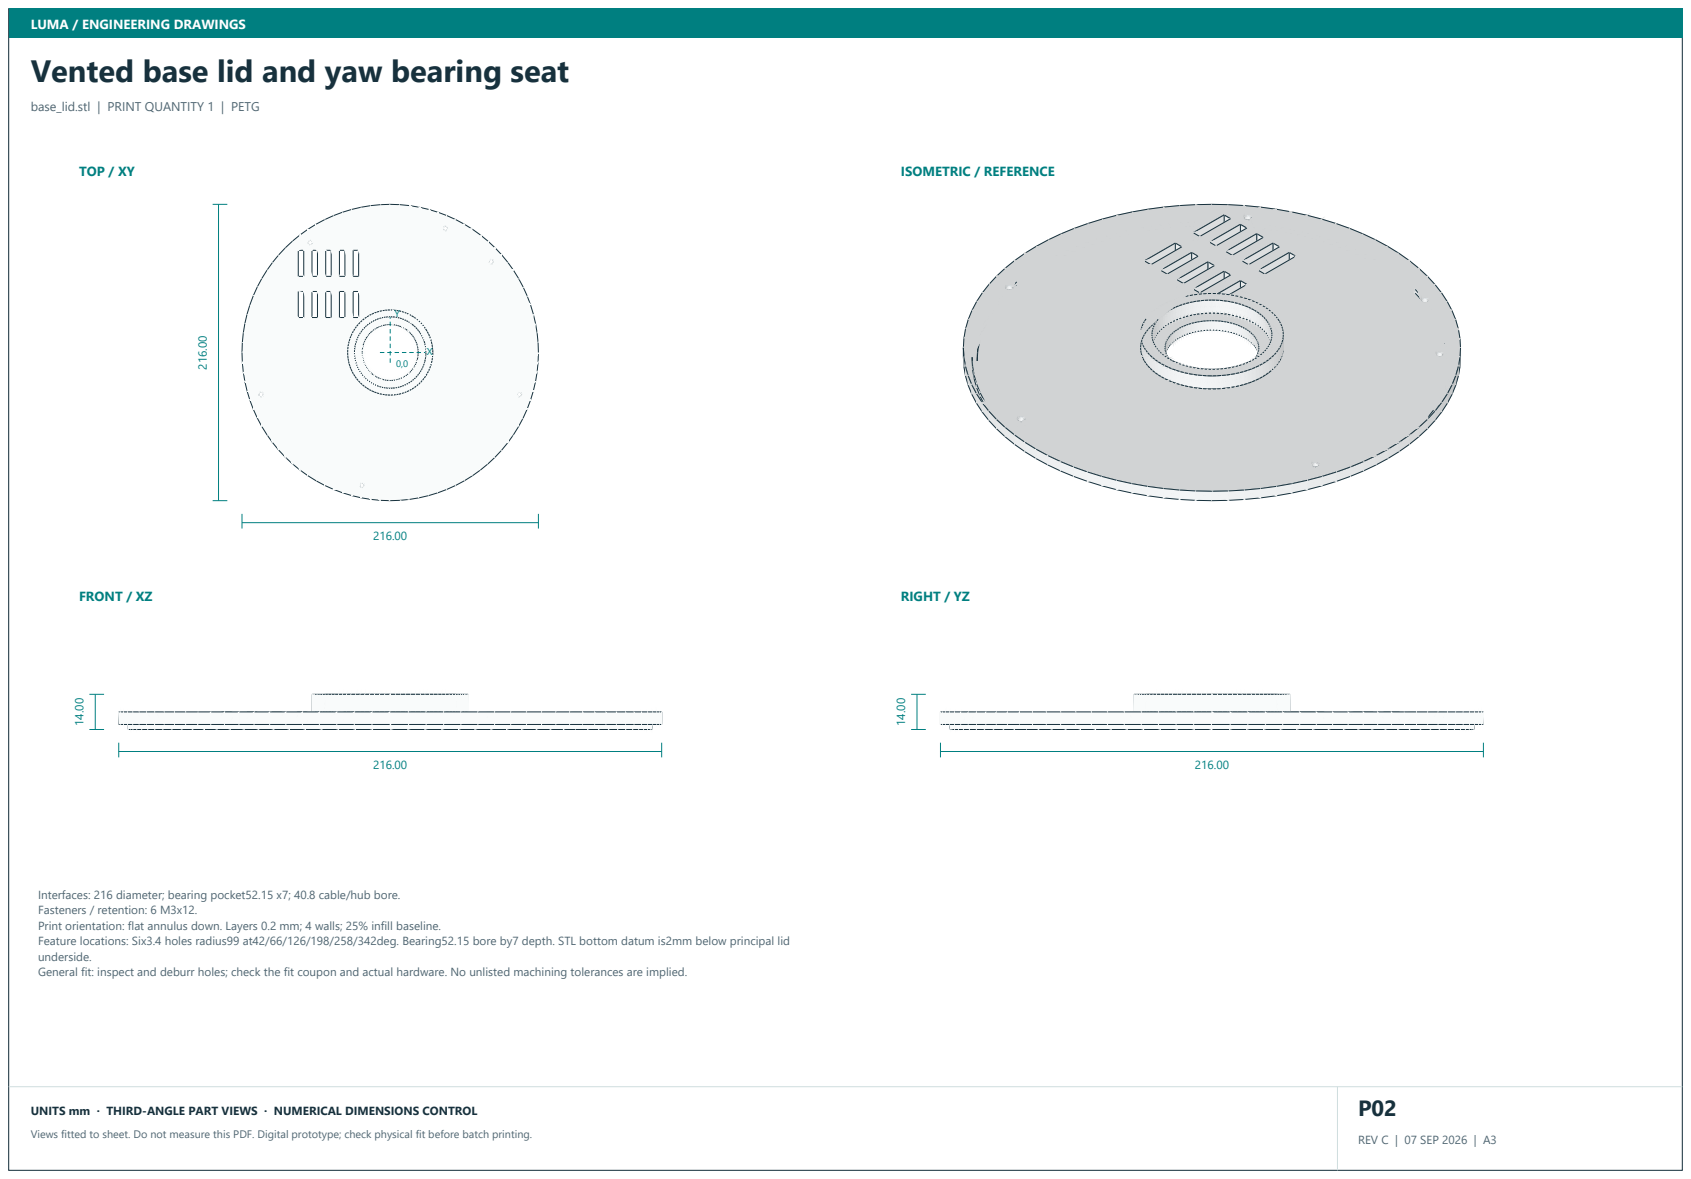
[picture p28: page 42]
TOP / XY; FRONT / XZ; RIGHT / YZ; ISOMETRIC / REFERENCE

base_lid.stl | PRINT QUANTITY 1 | PETG

Interfaces: 216 diameter; bearing pocket52.15 x7; 40.8 cable/hub bore.
Fasteners / retention: 6 M3x12.
Print orientation: flat annulus down. Layers 0.2 mm; 4 walls; 25% infill baseline.
Feature locations: Six3.4 holes radius99 at42/66/126/198/258/342deg. Bearing52.15 bore by7 depth. STL bottom datum is2mm below principal lid
underside.
General fit: inspect and deburr holes; check the fit coupon and actual hardware. No unlisted machining tolerances are implied.

# Universal electronics tray with Pi4 standoffs

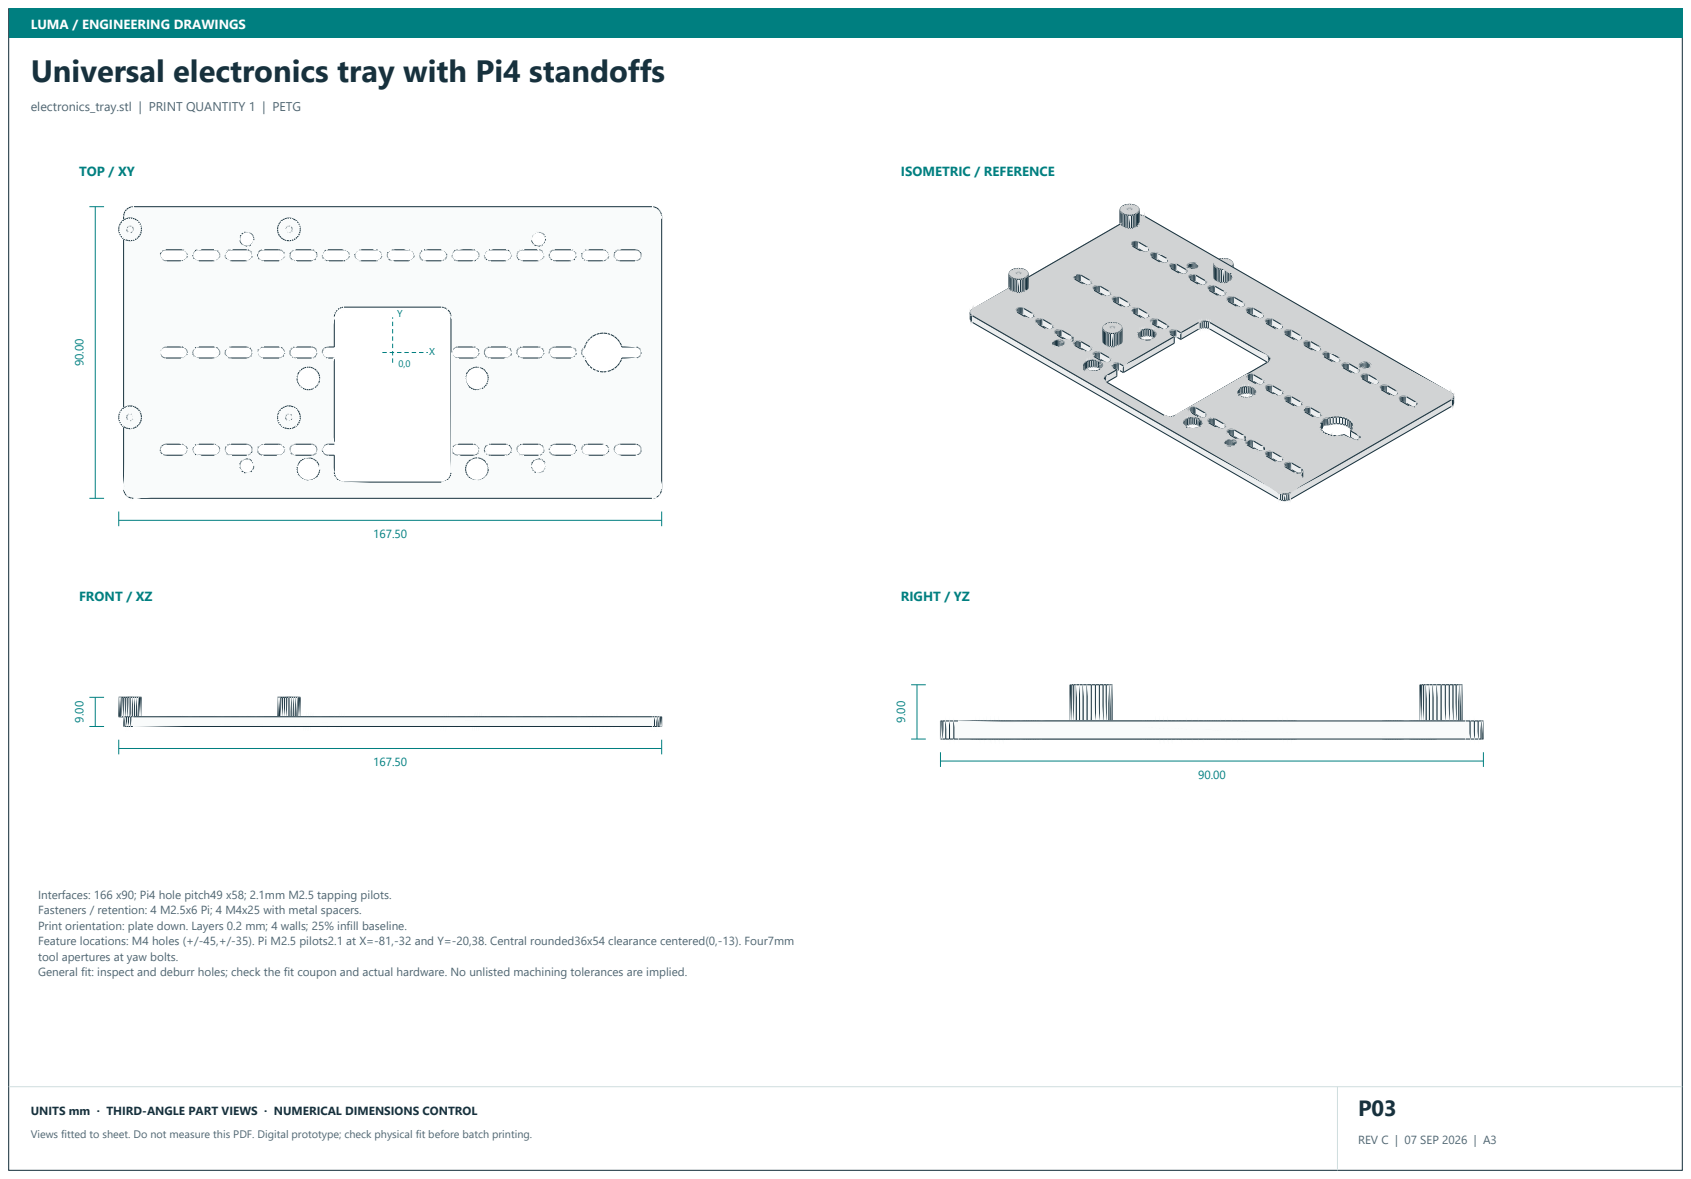
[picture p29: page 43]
TOP / XY; FRONT / XZ; RIGHT / YZ; ISOMETRIC / REFERENCE

electronics_tray.stl | PRINT QUANTITY 1 | PETG

Interfaces: 166 x90; Pi4 hole pitch49 x58; 2.1mm M2.5 tapping pilots.
Fasteners / retention: 4 M2.5x6 Pi; 4 M4x25 with metal spacers.
Print orientation: plate down. Layers 0.2 mm; 4 walls; 25% infill baseline.
Feature locations: M4 holes (+/-45,+/-35). Pi M2.5 pilots2.1 at X=-81,-32 and Y=-20,38. Central rounded36x54 clearance centered(0,-13). Four7mm
tool apertures at yaw bolts.
General fit: inspect and deburr holes; check the fit coupon and actual hardware. No unlisted machining tolerances are implied.

# DS3218MG yaw servo rear-body cradle

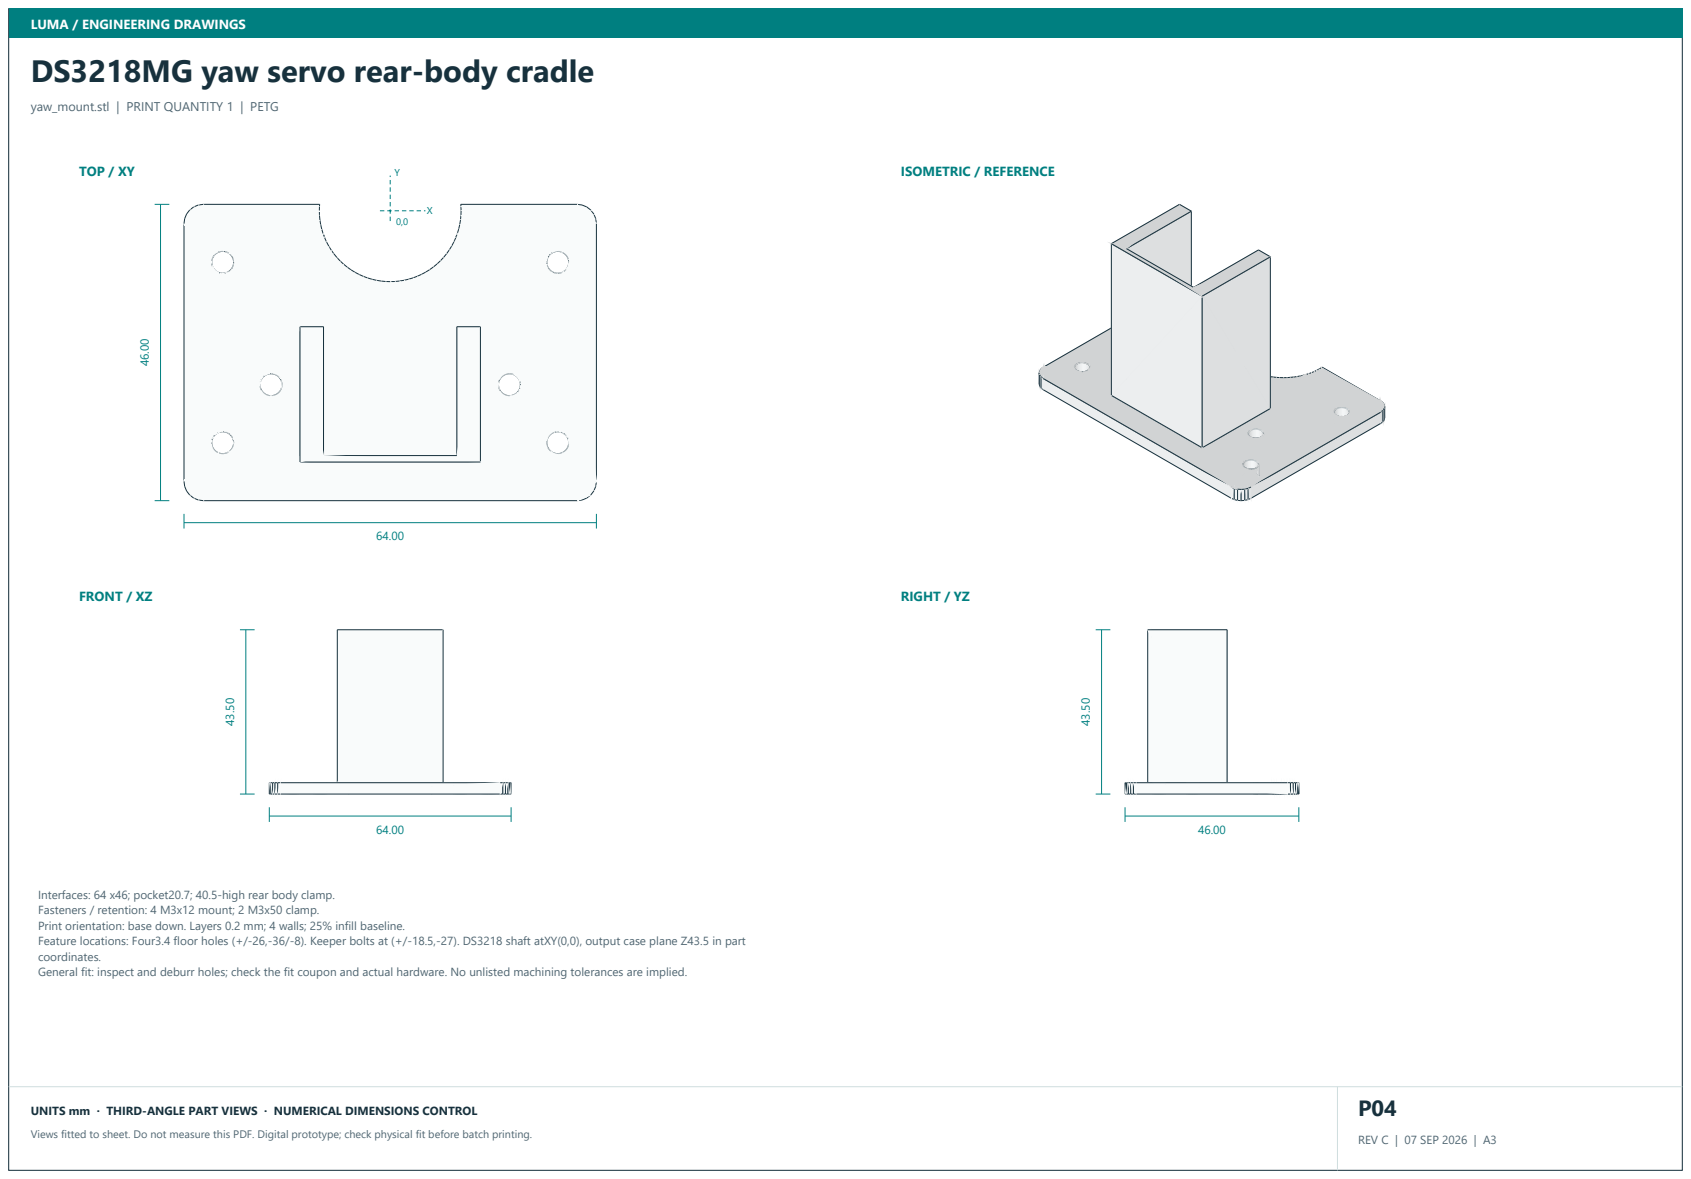
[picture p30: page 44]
TOP / XY; FRONT / XZ; RIGHT / YZ; ISOMETRIC / REFERENCE

yaw_mount.stl | PRINT QUANTITY 1 | PETG

Interfaces: 64 x46; pocket20.7; 40.5-high rear body clamp.
Fasteners / retention: 4 M3x12 mount; 2 M3x50 clamp.
Print orientation: base down. Layers 0.2 mm; 4 walls; 25% infill baseline.
Feature locations: Four3.4 floor holes (+/-26,-36/-8). Keeper bolts at (+/-18.5,-27). DS3218 shaft atXY(0,0), output case plane Z43.5 in part
coordinates.
General fit: inspect and deburr holes; check the fit coupon and actual hardware. No unlisted machining tolerances are implied.

# Yaw clamp keeper

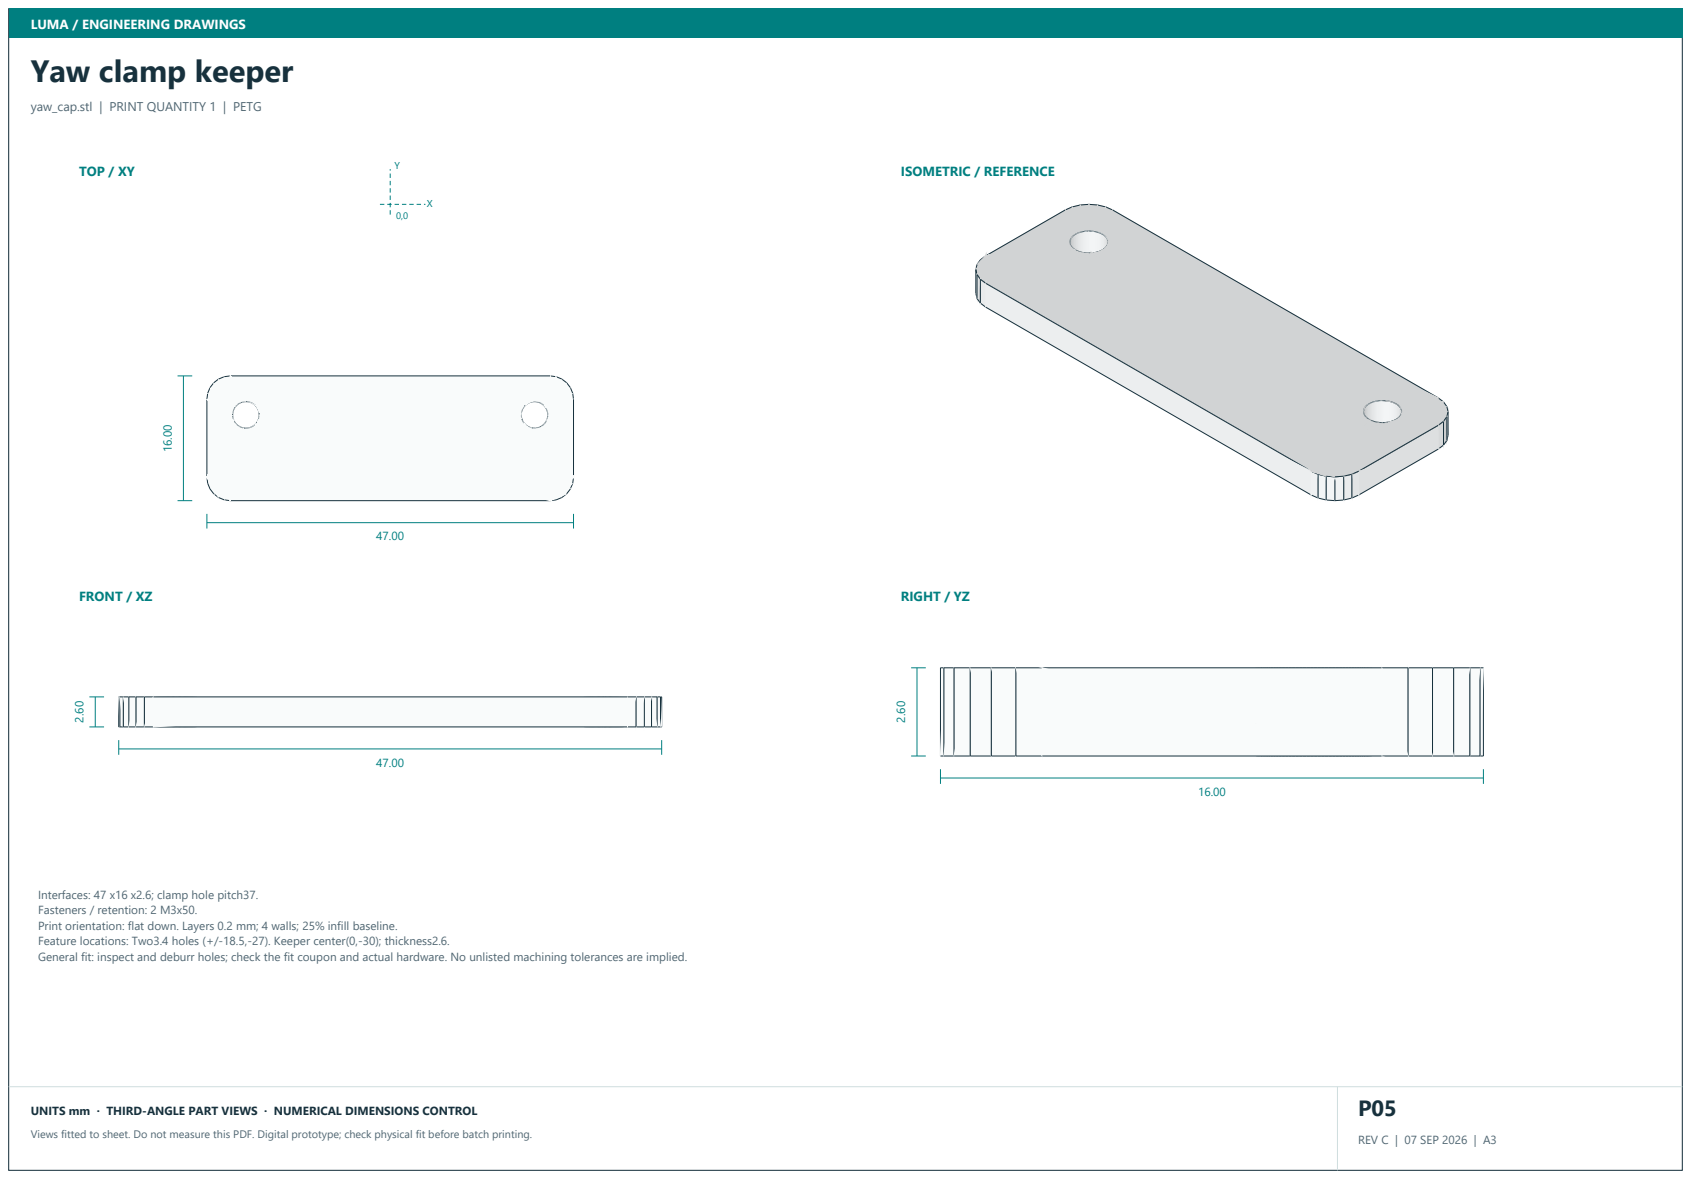
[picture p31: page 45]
TOP / XY; FRONT / XZ; RIGHT / YZ; ISOMETRIC / REFERENCE

yaw_cap.stl | PRINT QUANTITY 1 | PETG

Interfaces: 47 x16 x2.6; clamp hole pitch37.
Fasteners / retention: 2 M3x50.
Print orientation: flat down. Layers 0.2 mm; 4 walls; 25% infill baseline.
Feature locations: Two3.4 holes (+/-18.5,-27). Keeper center(0,-30); thickness2.6.
General fit: inspect and deburr holes; check the fit coupon and actual hardware. No unlisted machining tolerances are implied.

# Bearing-supported yaw turntable for straight servo arm

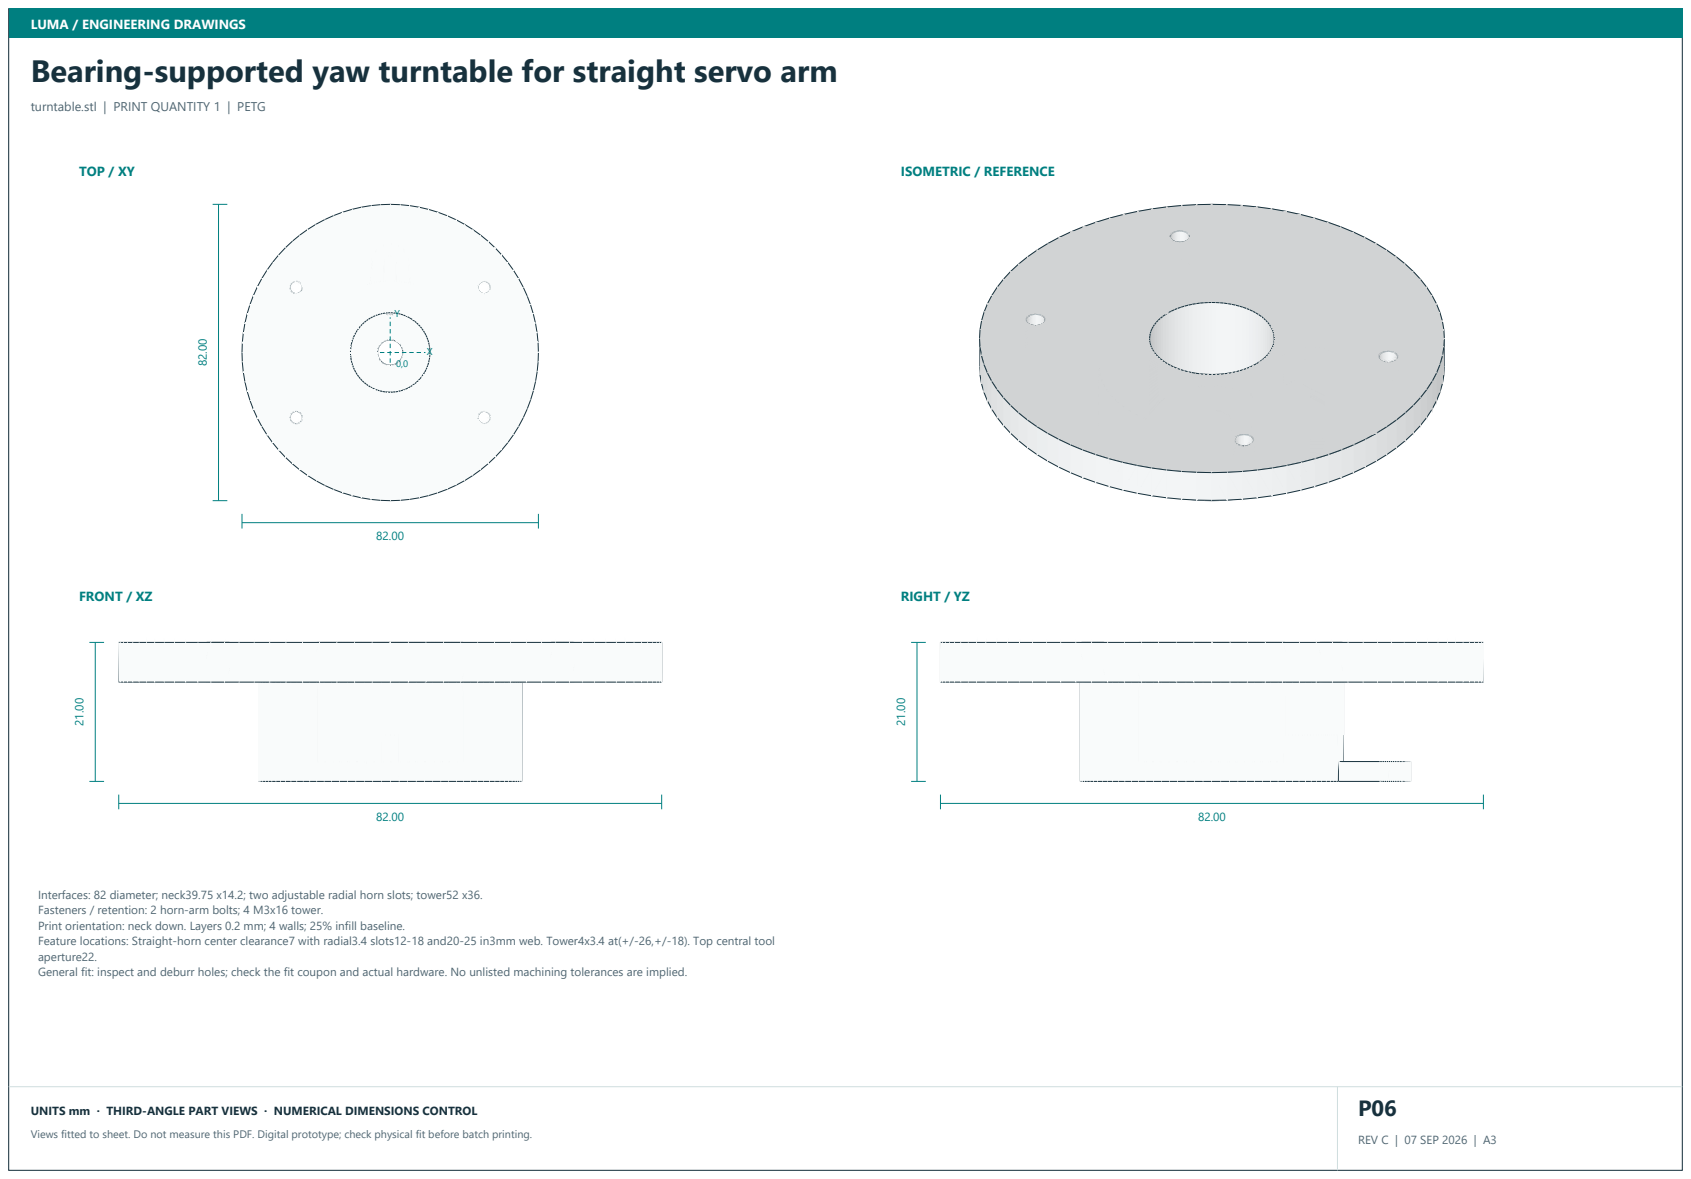
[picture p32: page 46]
TOP / XY; FRONT / XZ; RIGHT / YZ; ISOMETRIC / REFERENCE

turntable.stl | PRINT QUANTITY 1 | PETG

Interfaces: 82 diameter; neck39.75 x14.2; two adjustable radial horn slots; tower52 x36.
Fasteners / retention: 2 horn-arm bolts; 4 M3x16 tower.
Print orientation: neck down. Layers 0.2 mm; 4 walls; 25% infill baseline.
Feature locations: Straight-horn center clearance7 with radial3.4 slots12-18 and20-25 in3mm web. Tower4x3.4 at(+/-26,+/-18). Top central tool
aperture22.
General fit: inspect and deburr holes; check the fit coupon and actual hardware. No unlisted machining tolerances are implied.

# DS3218MG shoulder body tower with idler support

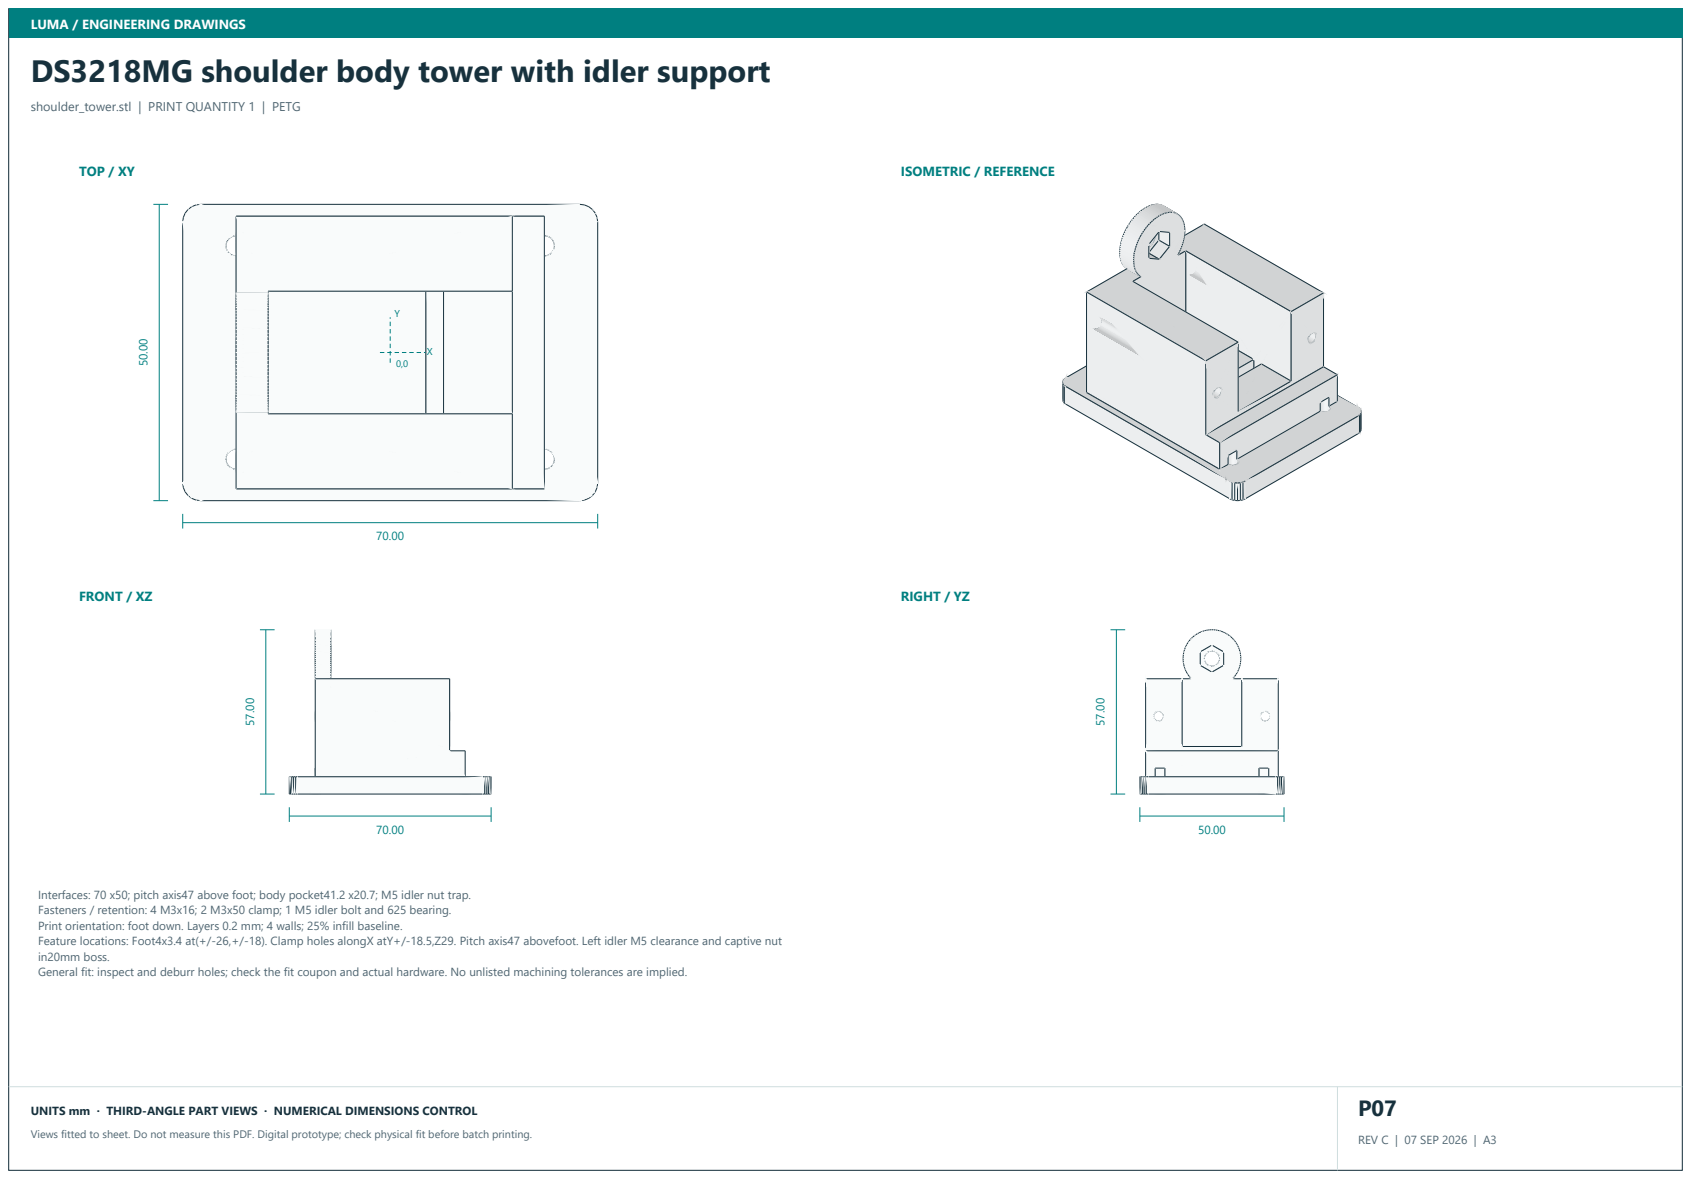
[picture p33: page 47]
TOP / XY; FRONT / XZ; RIGHT / YZ; ISOMETRIC / REFERENCE

shoulder_tower.stl | PRINT QUANTITY 1 | PETG

Interfaces: 70 x50; pitch axis47 above foot; body pocket41.2 x20.7; M5 idler nut trap.
Fasteners / retention: 4 M3x16; 2 M3x50 clamp; 1 M5 idler bolt and 625 bearing.
Print orientation: foot down. Layers 0.2 mm; 4 walls; 25% infill baseline.
Feature locations: Foot4x3.4 at(+/-26,+/-18). Clamp holes alongX atY+/-18.5,Z29. Pitch axis47 abovefoot. Left idler M5 clearance and captive nut
in20mm boss.
General fit: inspect and deburr holes; check the fit coupon and actual hardware. No unlisted machining tolerances are implied.

# Shoulder clamp keeper

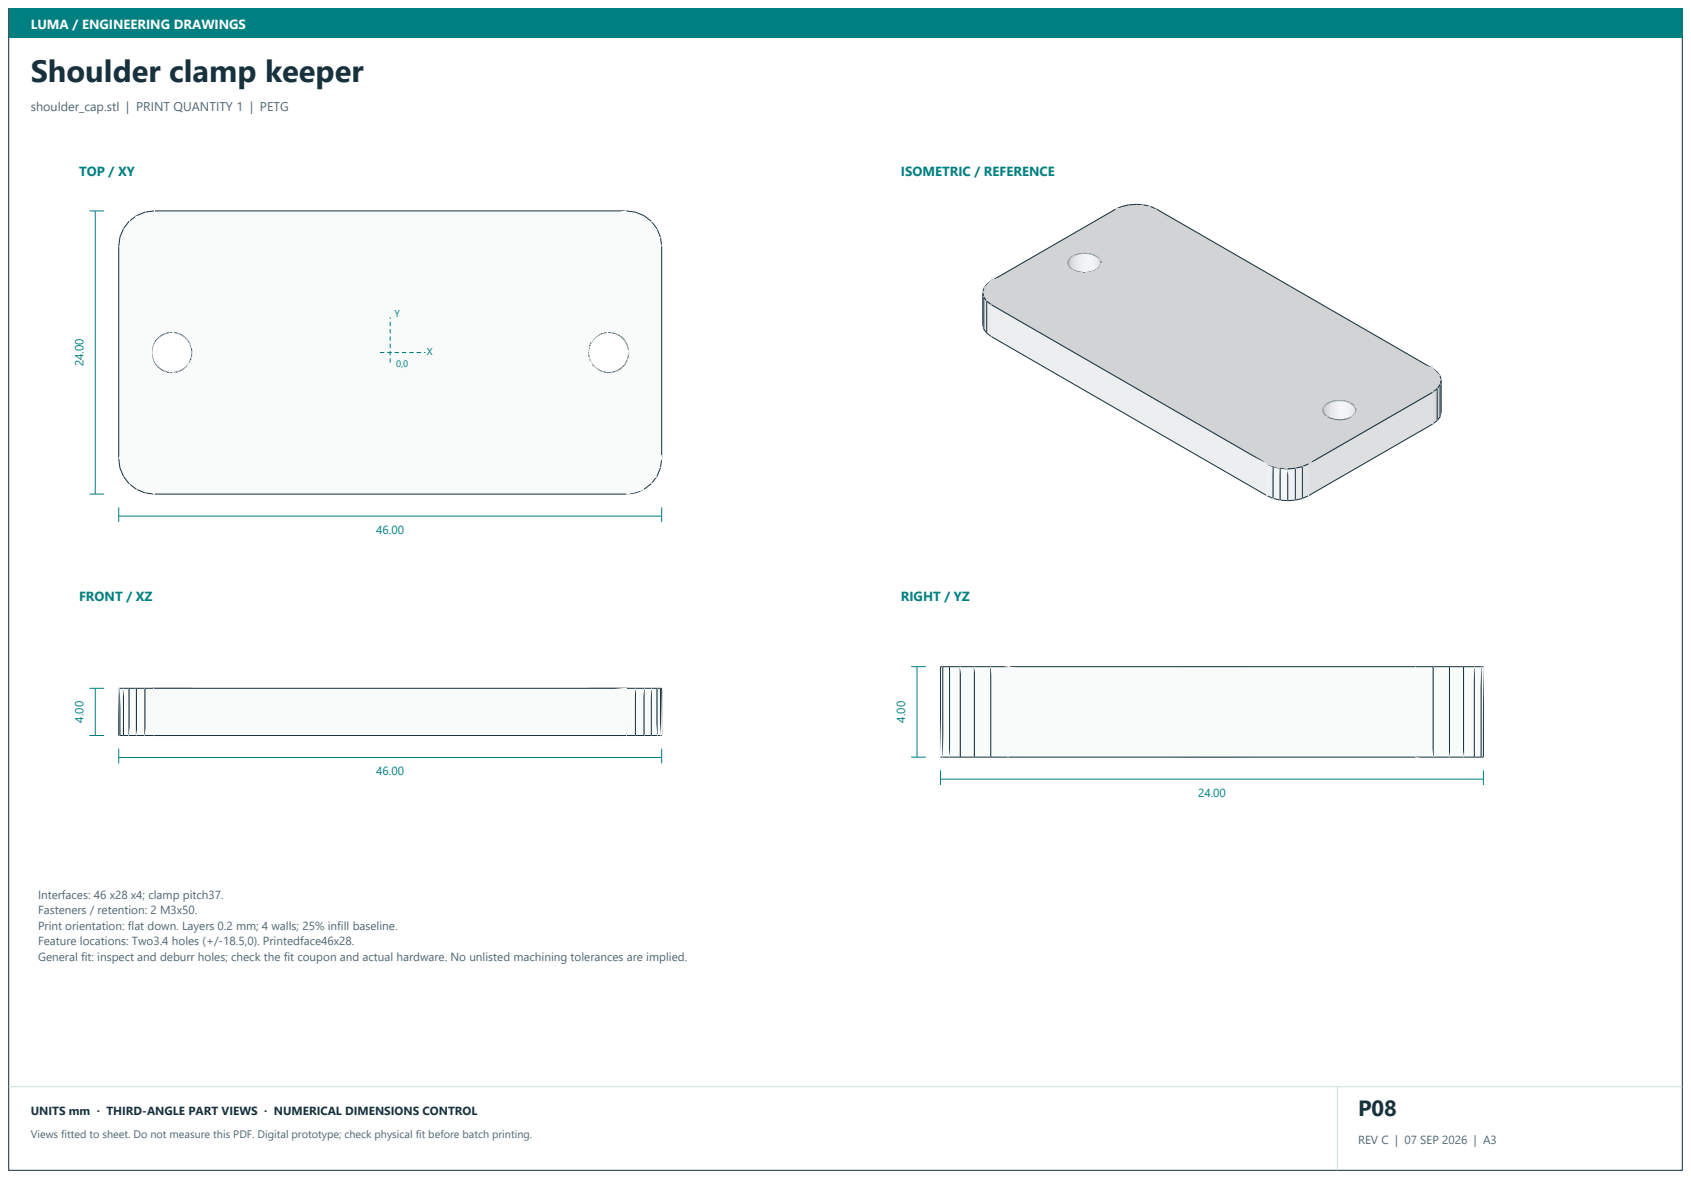
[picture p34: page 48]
TOP / XY; FRONT / XZ; RIGHT / YZ; ISOMETRIC / REFERENCE

shoulder_cap.stl | PRINT QUANTITY 1 | PETG

Interfaces: 46 x28 x4; clamp pitch37.
Fasteners / retention: 2 M3x50.
Print orientation: flat down. Layers 0.2 mm; 4 walls; 25% infill baseline.
Feature locations: Two3.4 holes (+/-18.5,0). Printedface46x28.
General fit: inspect and deburr holes; check the fit coupon and actual hardware. No unlisted machining tolerances are implied.

# Upper arm enclosed link, idler half

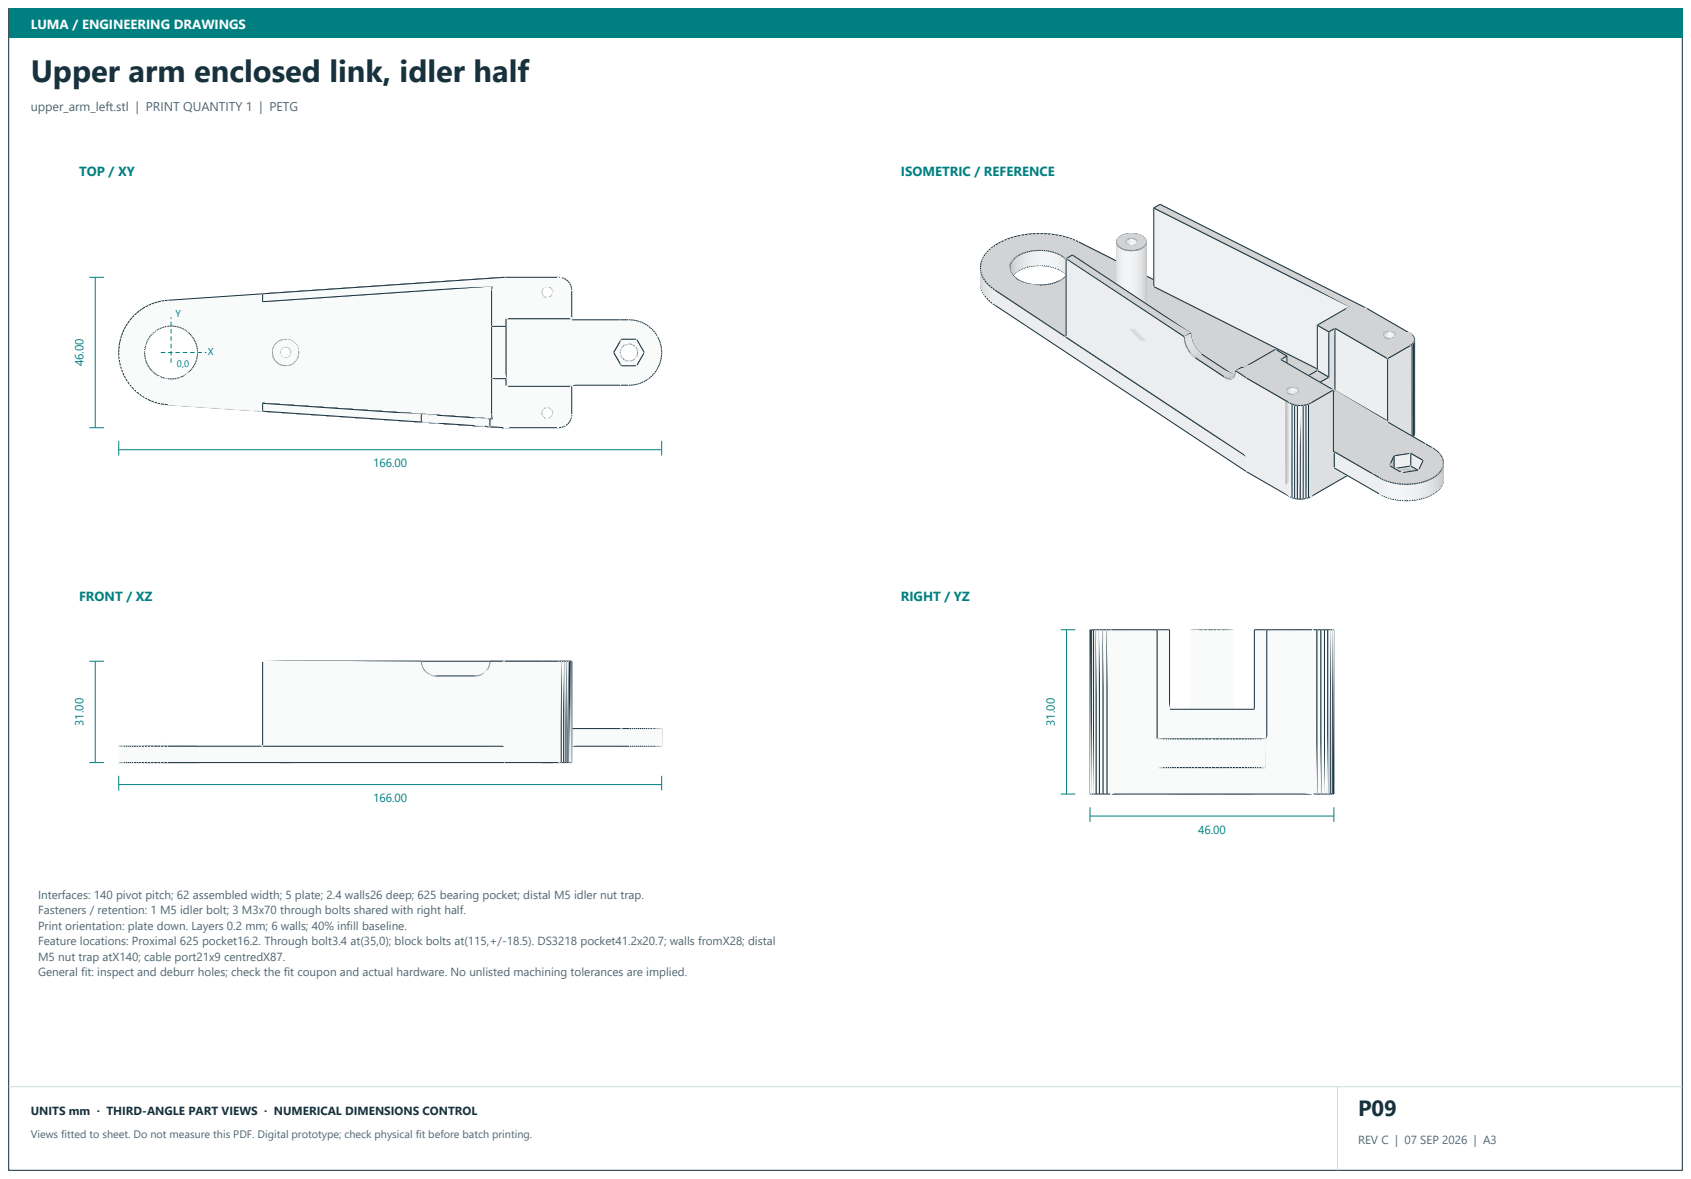
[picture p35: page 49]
TOP / XY; FRONT / XZ; RIGHT / YZ; ISOMETRIC / REFERENCE

upper_arm_left.stl | PRINT QUANTITY 1 | PETG

Interfaces: 140 pivot pitch; 62 assembled width; 5 plate; 2.4 walls26 deep; 625 bearing pocket; distal M5 idler nut trap.
Fasteners / retention: 1 M5 idler bolt; 3 M3x70 through bolts shared with right half.
Print orientation: plate down. Layers 0.2 mm; 6 walls; 40% infill baseline.
Feature locations: Proximal 625 pocket16.2. Through bolt3.4 at(35,0); block bolts at(115,+/-18.5). DS3218 pocket41.2x20.7; walls fromX28; distal
M5 nut trap atX140; cable port21x9 centredX87.
General fit: inspect and deburr holes; check the fit coupon and actual hardware. No unlisted machining tolerances are implied.

# Upper arm enclosed link, driven half

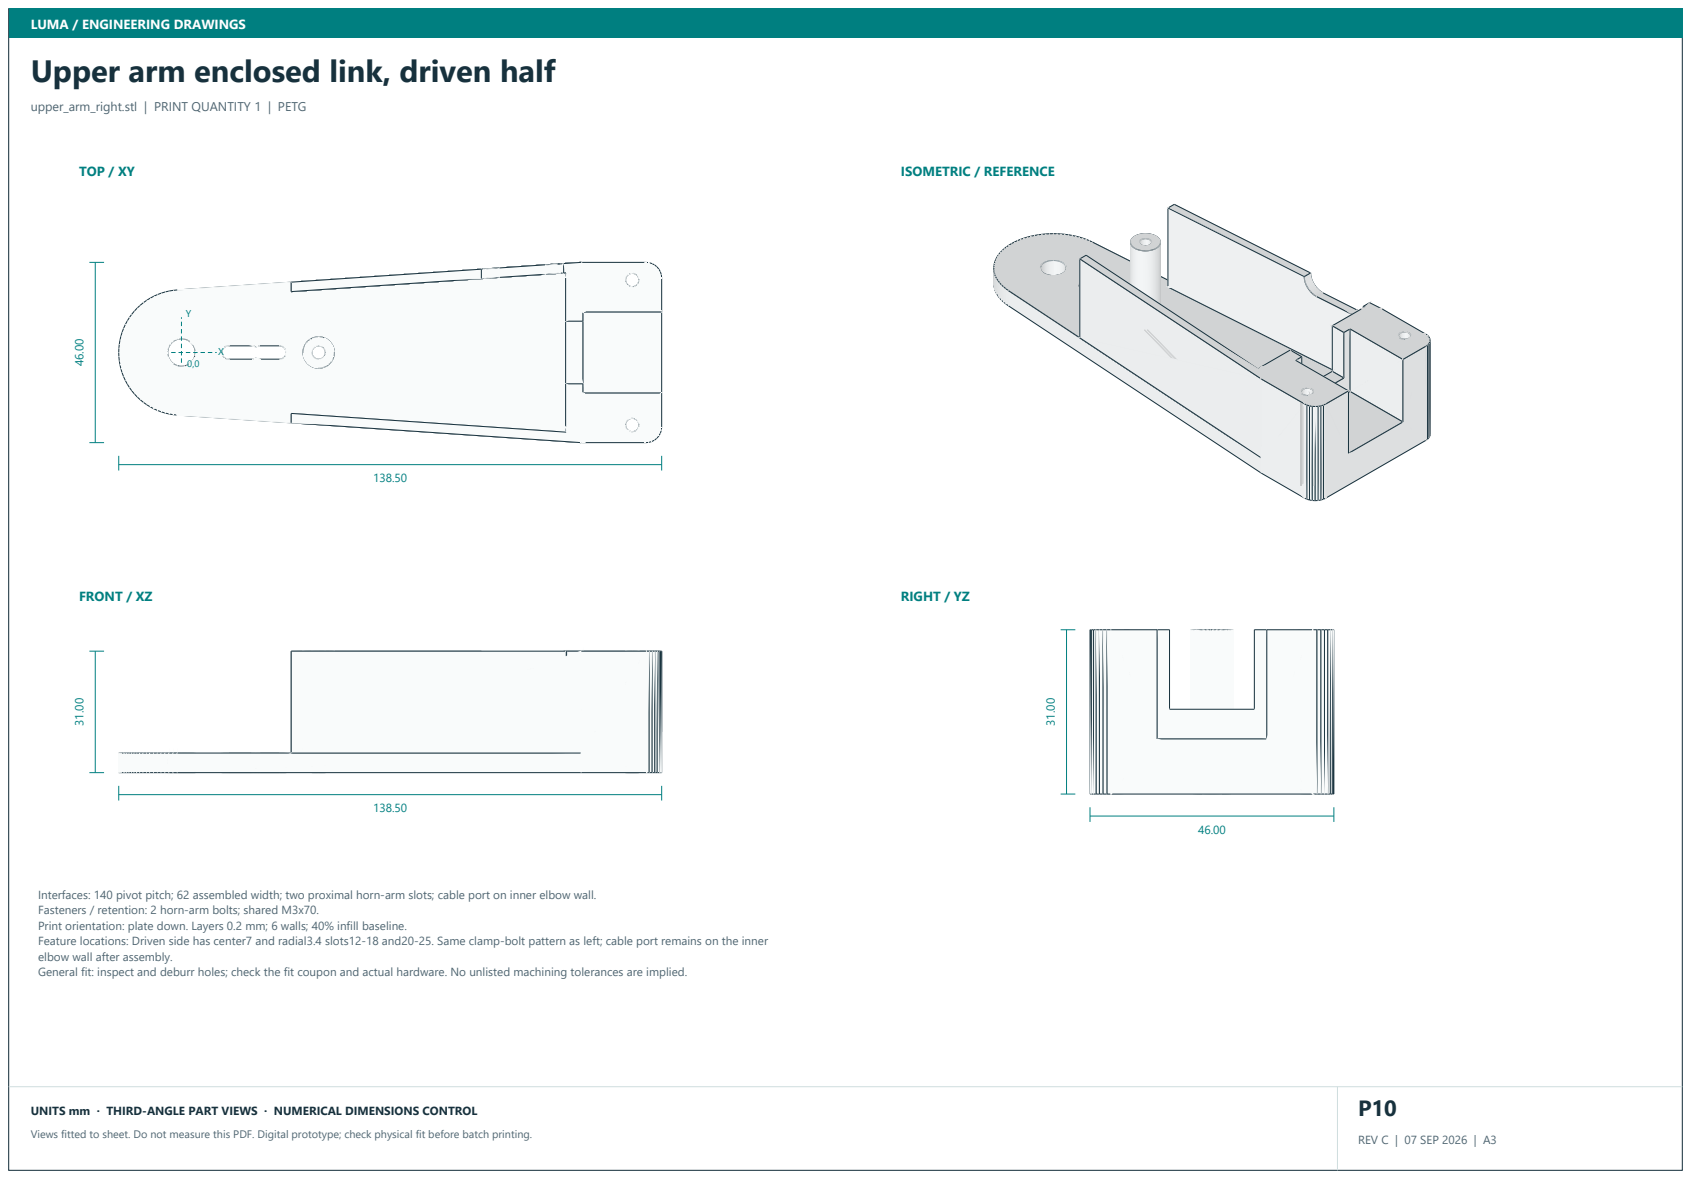
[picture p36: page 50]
TOP / XY; FRONT / XZ; RIGHT / YZ; ISOMETRIC / REFERENCE

upper_arm_right.stl | PRINT QUANTITY 1 | PETG

Interfaces: 140 pivot pitch; 62 assembled width; two proximal horn-arm slots; cable port on inner elbow wall.
Fasteners / retention: 2 horn-arm bolts; shared M3x70.
Print orientation: plate down. Layers 0.2 mm; 6 walls; 40% infill baseline.
Feature locations: Driven side has center7 and radial3.4 slots12-18 and20-25. Same clamp-bolt pattern as left; cable port remains on the inner
elbow wall after assembly.
General fit: inspect and deburr holes; check the fit coupon and actual hardware. No unlisted machining tolerances are implied.

# Forearm enclosed link, idler half

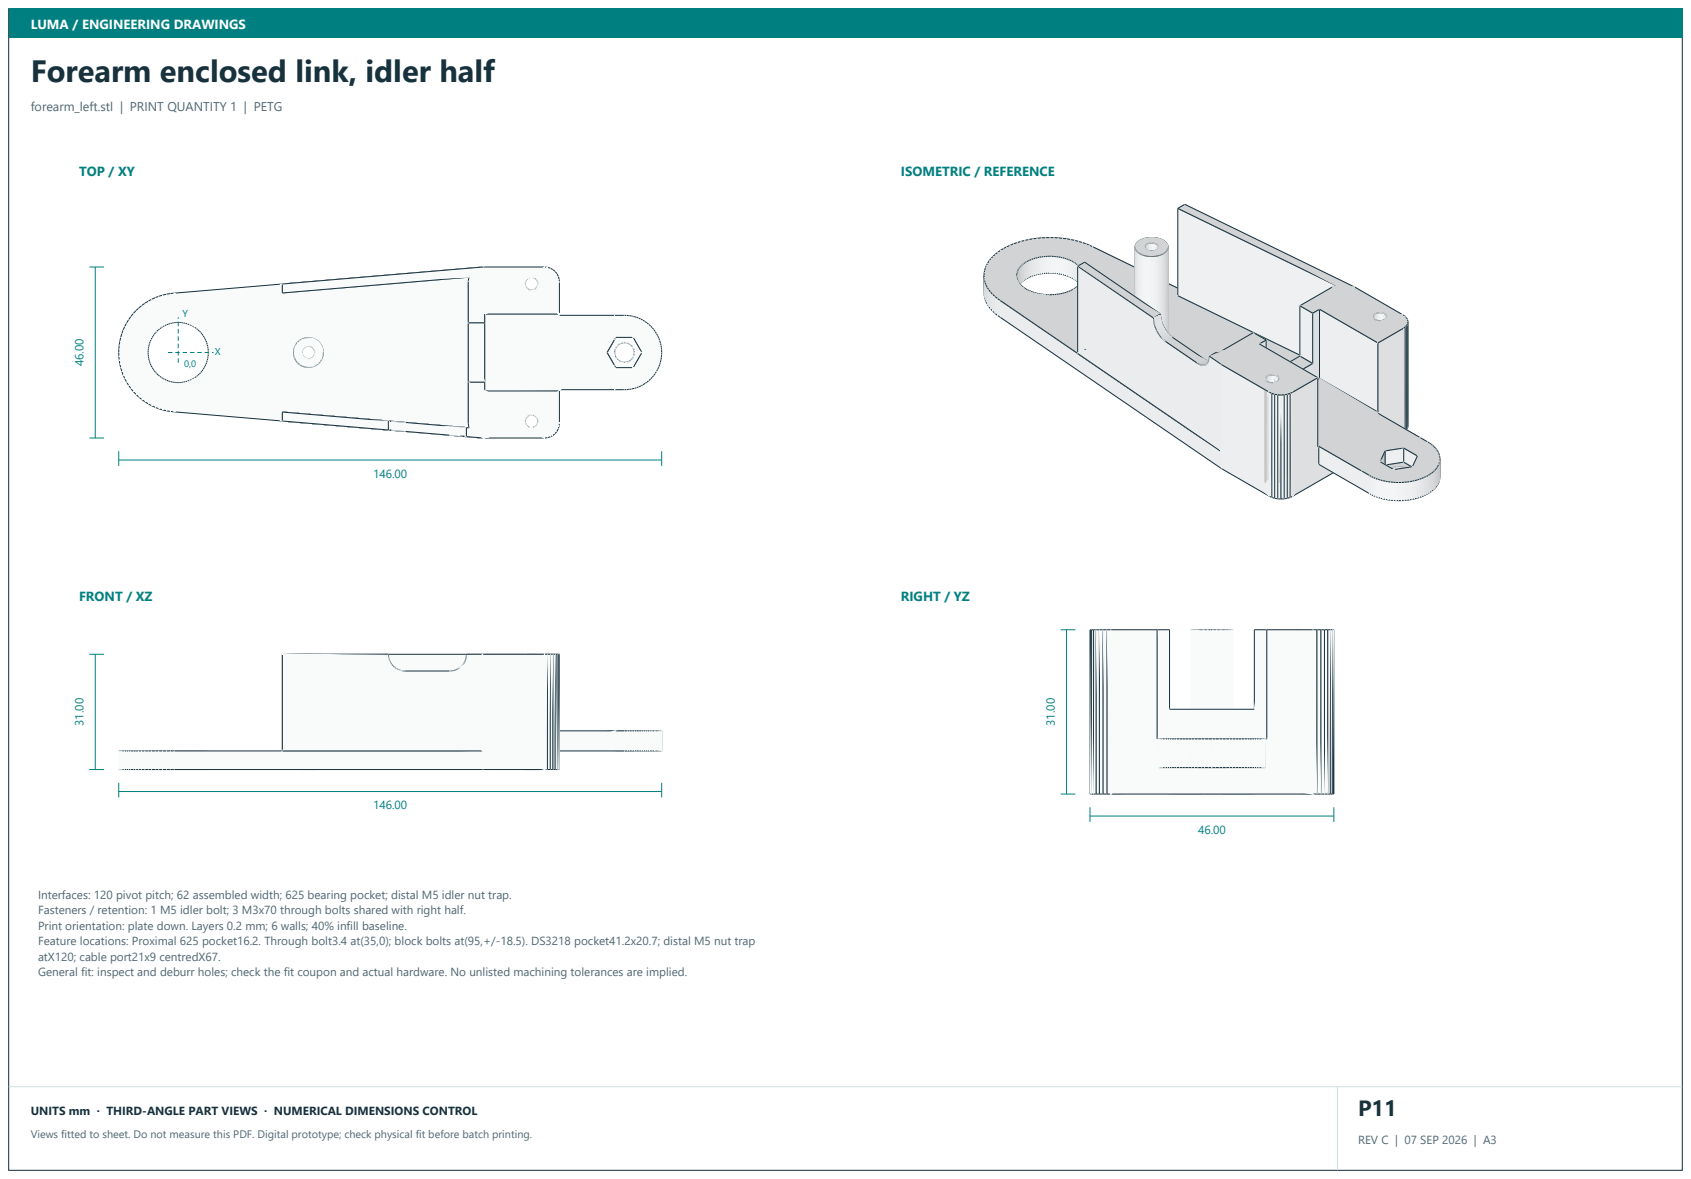
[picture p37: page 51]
TOP / XY; FRONT / XZ; RIGHT / YZ; ISOMETRIC / REFERENCE

forearm_left.stl | PRINT QUANTITY 1 | PETG

Interfaces: 120 pivot pitch; 62 assembled width; 625 bearing pocket; distal M5 idler nut trap.
Fasteners / retention: 1 M5 idler bolt; 3 M3x70 through bolts shared with right half.
Print orientation: plate down. Layers 0.2 mm; 6 walls; 40% infill baseline.
Feature locations: Proximal 625 pocket16.2. Through bolt3.4 at(35,0); block bolts at(95,+/-18.5). DS3218 pocket41.2x20.7; distal M5 nut trap
atX120; cable port21x9 centredX67.
General fit: inspect and deburr holes; check the fit coupon and actual hardware. No unlisted machining tolerances are implied.
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

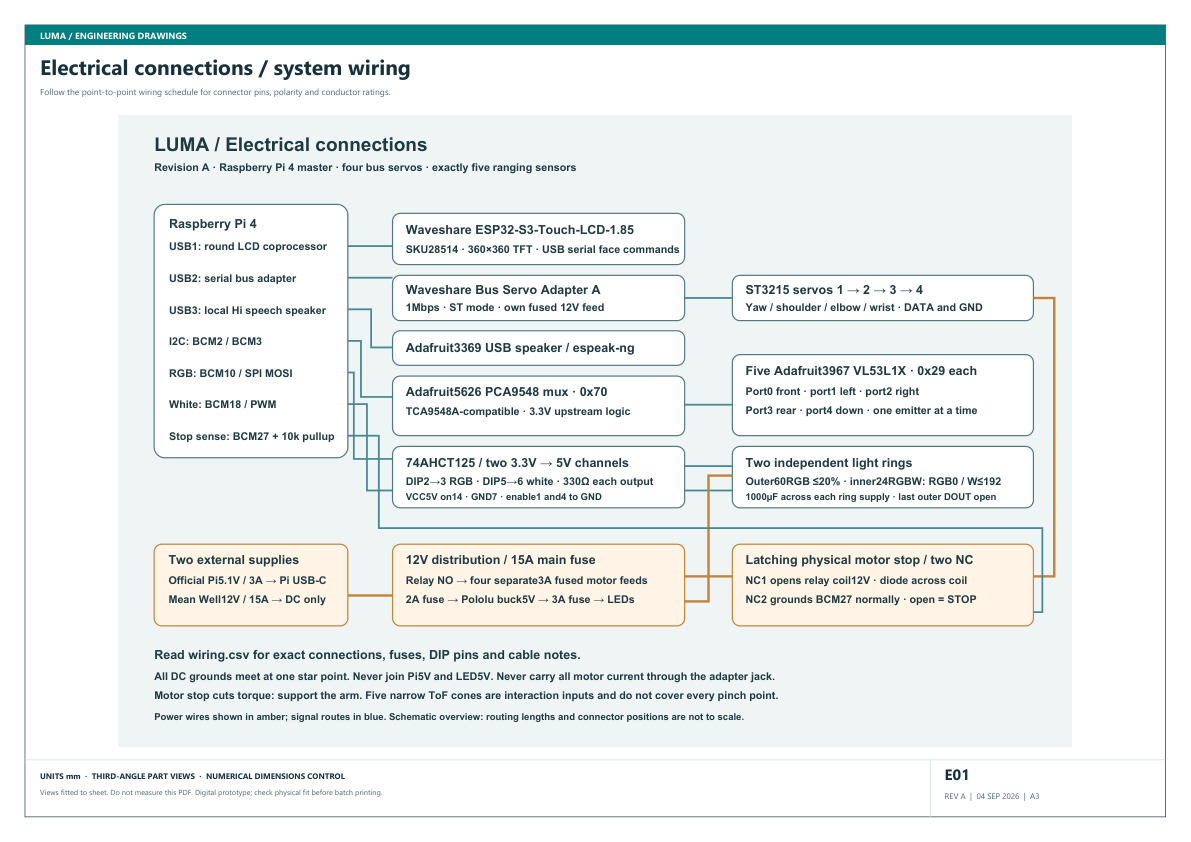
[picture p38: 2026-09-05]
validation/wiring_drawing_preview.png

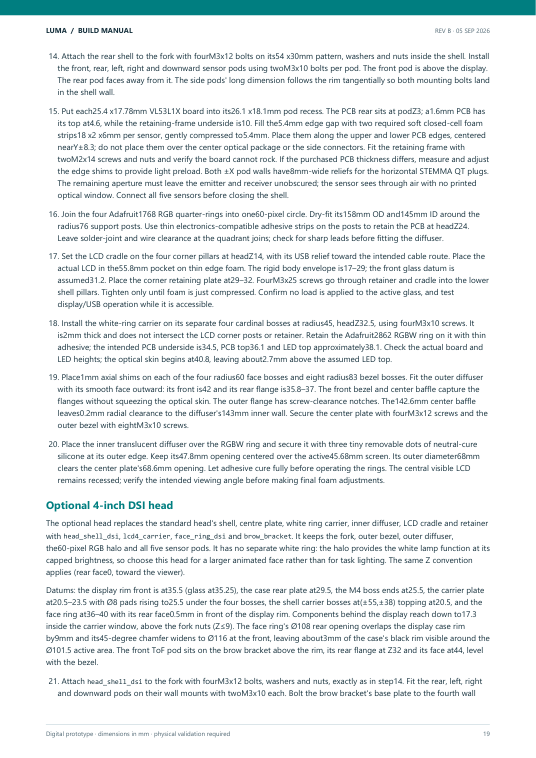
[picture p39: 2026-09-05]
validation/manual_dsi_page_preview.png

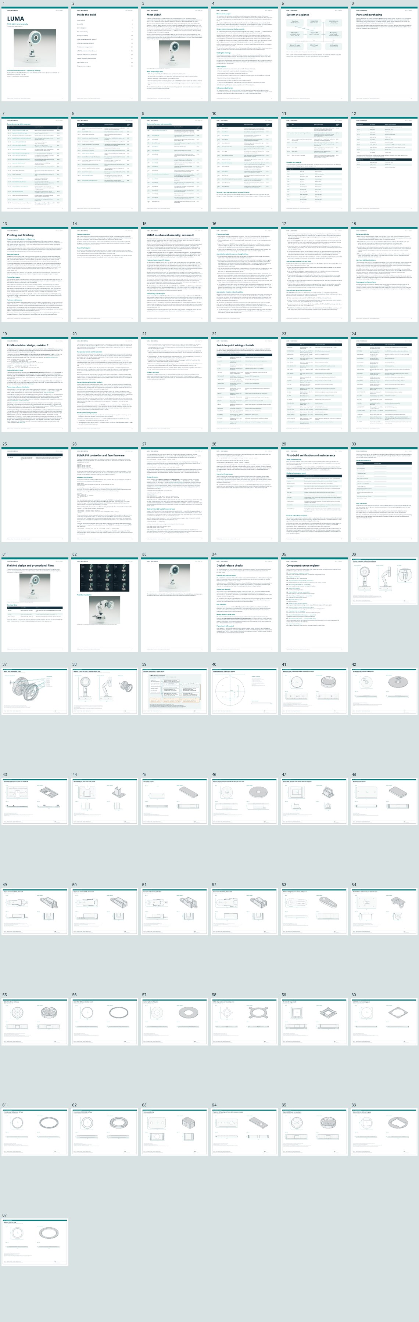
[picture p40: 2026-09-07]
validation/manual_contact_sheet.jpg

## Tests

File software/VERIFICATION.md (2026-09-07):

# Verification record

Date:2026-09-07. Development host:Windows, Python3.13.14.

`python -m unittest discover -s tests -v`: **38 tests passed**. Coverage includes three-scene joint limits and12°/s slew, all five pedestal sensor names/order, stale/NaN/no-return/near faults, paired rear and front-side gestures, latched holds, motor-stop polarity, display/PCA9685 communication faults, one-shot speech, and RGBW white-only limits.

PWM tests cover the DS3218's500-2500µs/270° conversion, a known50Hz PCA9685 duty value, four unique configured channels, calibrated neutral gating, neutral command on arm, last-command hold semantics, and a one-channel commissioning command that disables the other three outputs. The PCA9685 driver is imported only when hardware is opened. Tests do not claim real PWM timing or servo motion.

Face tests draw the standard expression logic for the optional720×720 DSI head onto an off-screen surface and check eye, blush, mouth, offline and fault pixels. `DsiDisplay` is exercised with SDL's dummy driver. Importing the main hardware module does not import pygame unless the DSI path is selected.

`python -m luma.app --scene hi --seconds 1` is the non-hardware simulator check. It prints one Hi event, bounded joint motion, W192 and no fault. The test suite also runs the wink/happy trajectories for500 frames each.

The Raspberry Pi, PCA9685, DS3218MG servos,6V regulator, sensors, stop relay, screens and light rings were not present in this development workspace. No physical I2C, PWM, position, current, torque, optical or thermal result is claimed. The PCA9685 can report controller communication but the selected servos provide no readable shaft, load, current or temperature feedback.

The standard display source targets Waveshare SKU28514 and contains both documented panel initialization tables. **Cross-compilation remains unverified.** The earlier PlatformIO compiler download did not complete and an alternate download was truncated. No firmware binary or physical display test is claimed.

The optional Waveshare4inch DSI LCD(C) path remains digitally verified only through pygame's dummy driver. Actual `kmsdrm` output, vendor overlays, panel rotation, touch/backlight control and the800mm DSI FPC run require the physical Pi and display.

Run the one-channel servo check only with the horn disconnected from the arm:

```console
.venv/bin/python -m luma.bench servo --joint yaw --pulse-us 1500 --seconds 2 --confirm-unloaded
```

The command is bounded to10seconds, disables all non-selected channels, and removes the selected PWM pulse on exit. It does not limit motor current or detect shaft motion. Use the independent motor stop and the regulated fused6V rail described in the electrical chapter.

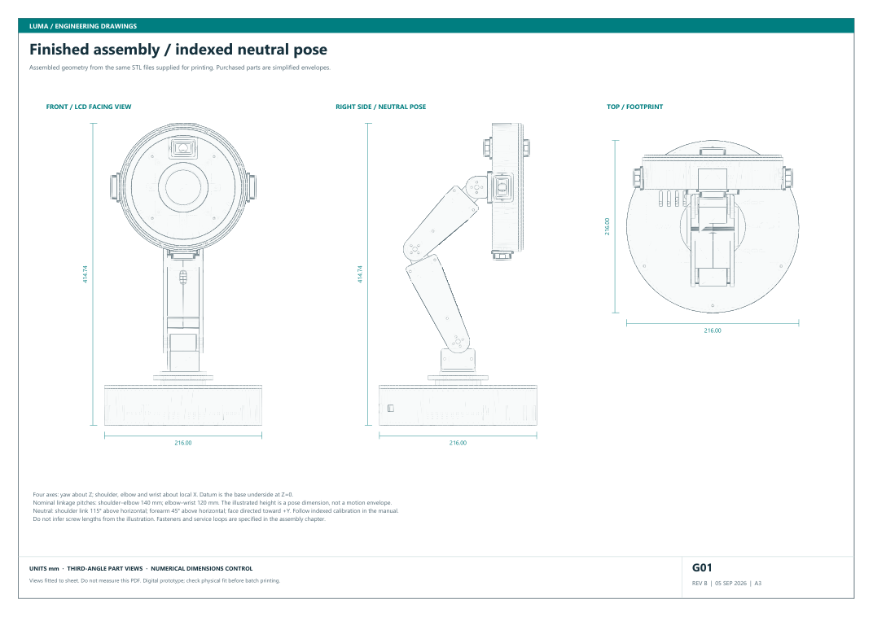
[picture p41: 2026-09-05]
validation/drawing_preview_p1.png

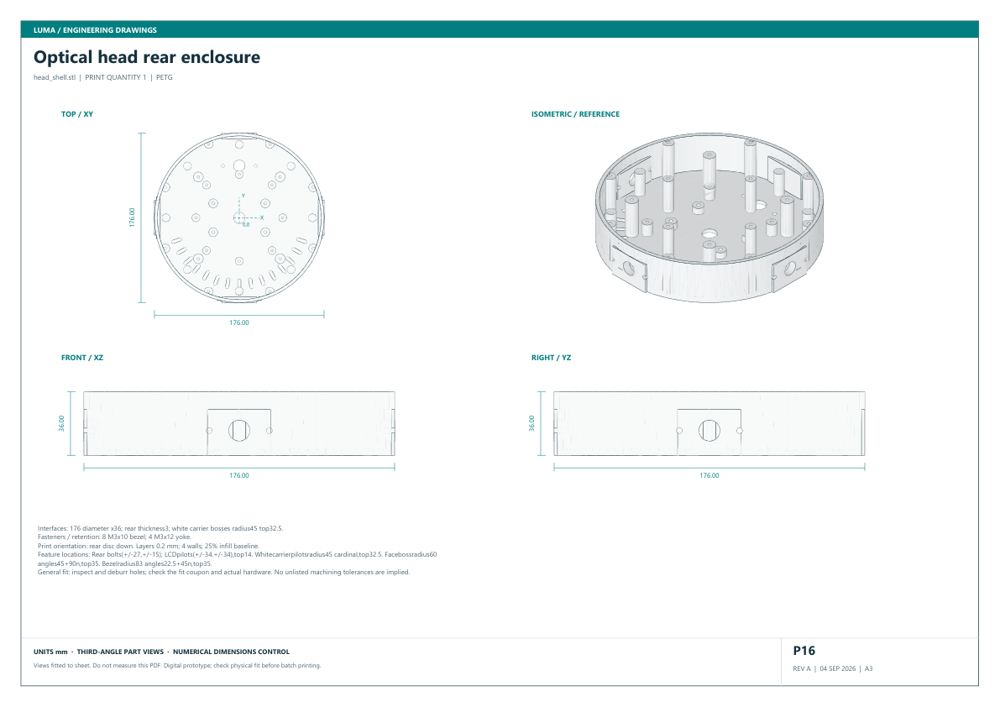
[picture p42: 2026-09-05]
validation/head_drawing_preview.png

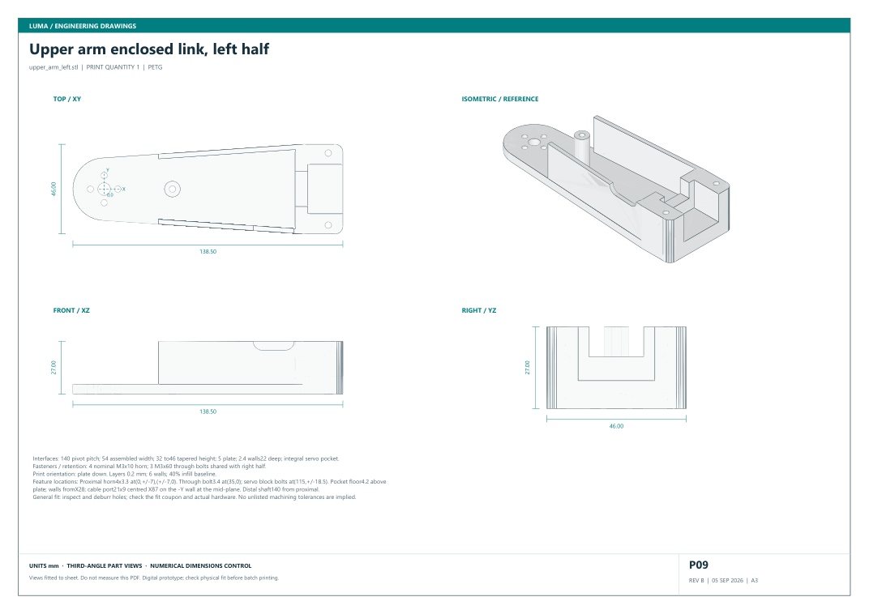
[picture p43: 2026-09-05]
validation/drawing_preview_p14.png

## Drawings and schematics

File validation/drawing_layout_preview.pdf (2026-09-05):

# 140 mm upper arm side rail

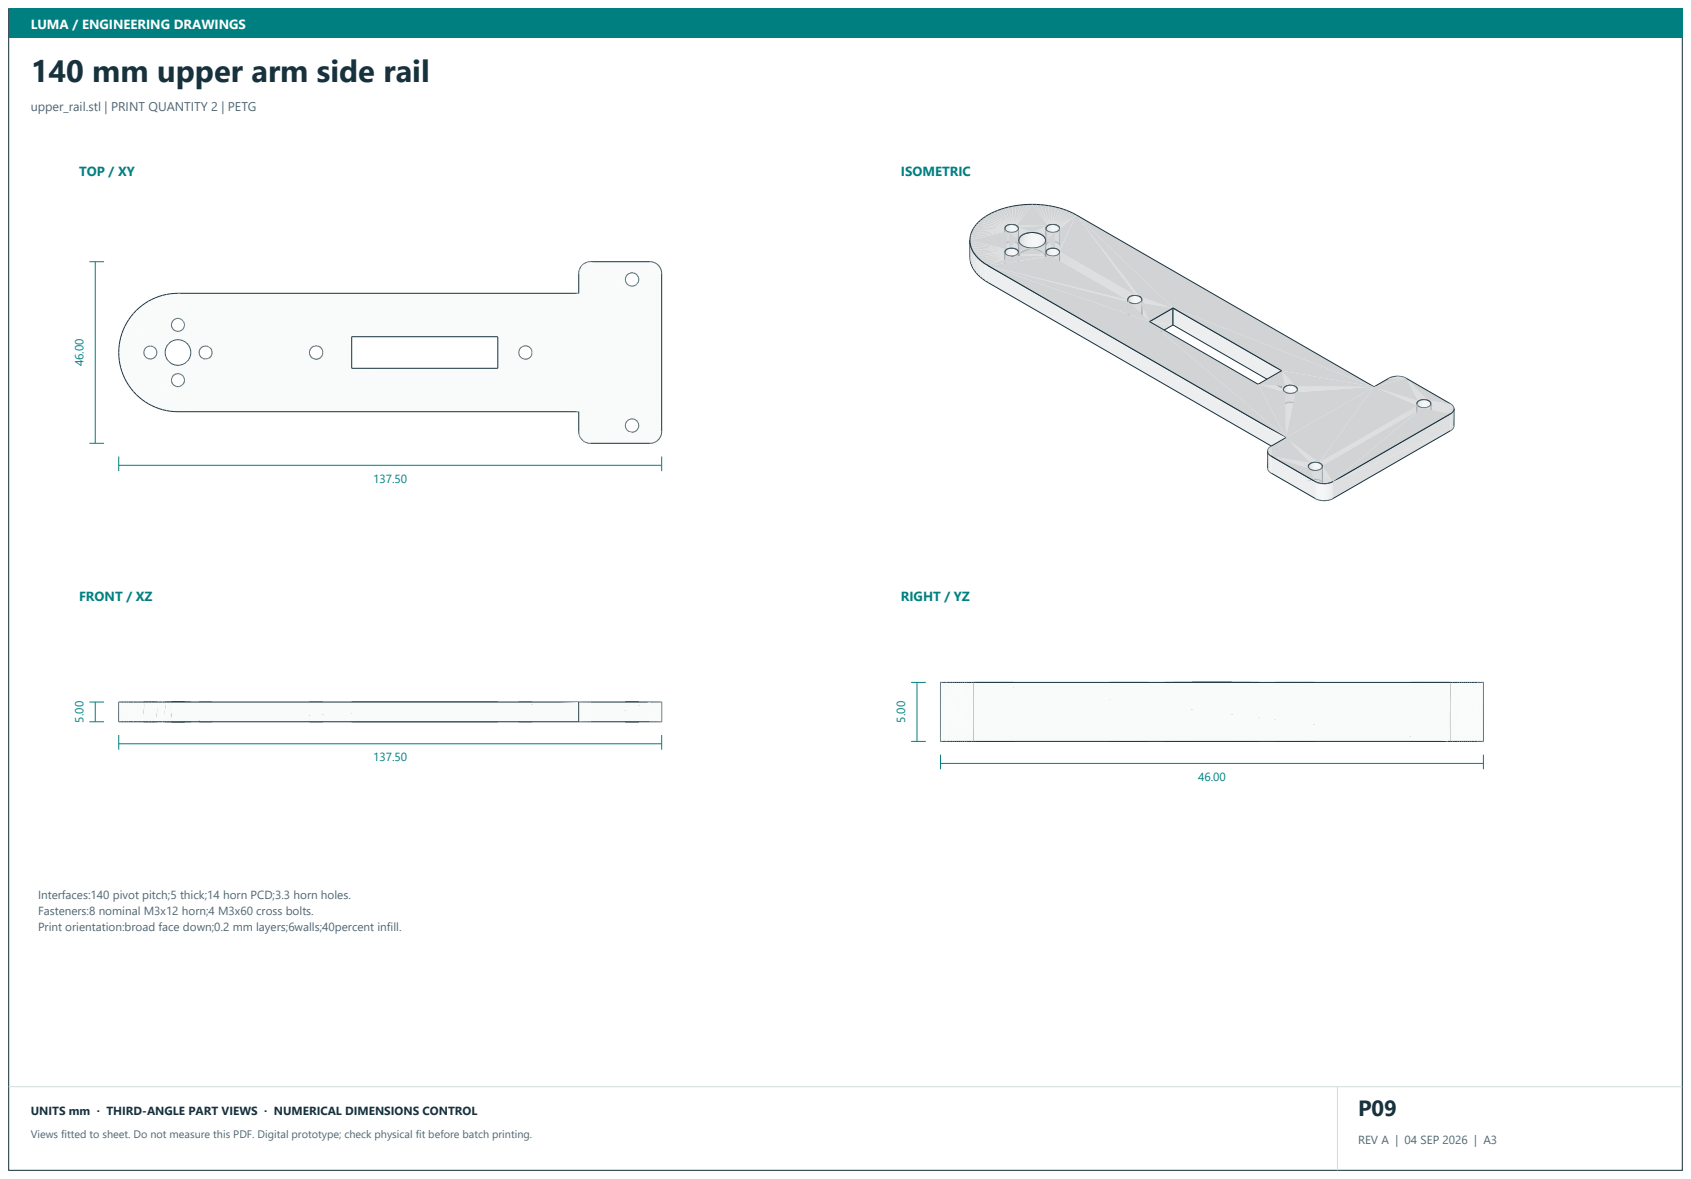
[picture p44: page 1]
REV A | 04 SEP 2026 | A3; TOP / XY; FRONT / XZ; RIGHT / YZ; ISOMETRIC

LUMA / ENGINEERING DRAWINGS

upper_rail.stl | PRINT QUANTITY 2 | PETG

Interfaces:140 pivot pitch;5 thick;14 horn PCD;3.3 horn holes.
Fasteners:8 nominal M3x12 horn;4 M3x60 cross bolts.
Print orientation:broad face down;0.2 mm layers;6walls;40percent infill.

UNITS mm · THIRD-ANGLE PART VIEWS · NUMERICAL DIMENSIONS CONTROL

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

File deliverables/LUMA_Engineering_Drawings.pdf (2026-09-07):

LUMA / ENGINEERING DRAWINGS

# Finished assembly / indexed neutral pose

Assembled geometry from the same STL files supplied for printing. Purchased parts are simplified envelopes.

UNITS mm · THIRD-ANGLE PART VIEWS · NUMERICAL DIMENSIONS CONTROL

Views fitted to sheet. Do not measure this PDF. Digital prototype; check physical fit before batch printing.

G01

REV C | 07 SEP 2026 | A3

FRONT / LCD FACING VIEW

216.00

420.74

RIGHT SIDE / NEUTRAL POSE

216.00

420.74

TOP / FOOTPRINT

216.00

216.00

Four axes: yaw about Z; shoulder, elbow and wrist about local X. Datum is the base underside at Z=0.
Nominal linkage pitches: shoulder–elbow 140 mm; elbow–wrist 120 mm. The illustrated height is a pose dimension, not a motion envelope. Neutral: shoulder link 115° above horizontal; forearm 45° above horizontal; face directed toward +Y. Follow indexed calibration in the manual.
Five Adafruit3967 boards mount inside the pedestal wall. Four DS3218MG servos use driven straight horns and opposite625 supports at pitch joints. Do not infer screw lengths from the illustration. Fasteners and service loops are specified in the assembly chapter.

# Head / layered assembly study

Exploded positions expose the optical parts; displacements are illustrative and are not insertion paths.

G02

EXPLODED HEAD / MODEL-DERIVED VIEW

## LAYER REFERENCES

01 Head tilt fork

02 head driven horn spacer

03 Head Shell

04 Outer Bezel

05 Face Center

06 White Carrier

07 Lcd Cradle

08 Lcd Retainer

09 Outer Diffuser

10 Inner Diffuser

11 Purchased LCD envelope

Central LCD board is behind the inner white ring. Keep all optical components at their documented axial heights.
Use natural PETG for both light diffusers and opaque PETG for the optical baffle. Leave LCD glass clear; all ToF apertures are in the pedestal. The four outer ring PCB quarters require continuous mechanical support. Solder joints are electrical connections only.
Refer to the head assembly chapter for screw order, spacers, wire relief and board retention. Purchased LEDs are not printable parts.

# Optional 4-inch DSI head / indexed neutral pose

Same sensor-equipped pedestal, arm links and fork as G01. Head shell, carrier and face ring are the optional parts; the display envelope is measured from the vendor STEP.

G03

FRONT / LCD FACING VIEW

216.00

420.74

RIGHT SIDE / NEUTRAL POSE

216.00

420.74

EXPLODED DSI HEAD

Waveshare 4inch DSI LCD (C): Ø126 case, 6 mm thick, four M4 bosses on a 75 × 75 pattern. Rim front at head Z35.5; carrier plate Z20.5–23.5 with pads to the boss ends at Z25.5.
Face ring opening Ø108 chamfered to Ø116 leaves a 3 mm black rim around the Ø101.5 active area. Outer60-RGB halo, bezel, diffuser and fork are shared with the standard head.
No inner white ring on this head: the halo provides capped white output. Revision C has no head-mounted sensors or brow bracket.
Cables: 15-pin DSI FFC plus 5 V/GND leave through the 26 × 8 slot in the shell floor and fork plate, then run inside the enclosed links through their wall ports.

# Electrical connections / system wiring

Follow the point-to-point wiring schedule for connector pins, polarity and conductor ratings.

E01

# LUMA / Electrical connections

## Revision C · Raspberry Pi 4 master · four PWM servos · five pedestal-wall ranging sensors

## Raspberry Pi 4

## USB1: round LCD coprocessor

## I2C0x40: PCA9685 servo PWM

## USB3: local Hi speech speaker

## I2C0x70: five-channel sensor mux

## RGB: BCM10 / SPI MOSI

## White: BCM18 / PWM

## Stop sense: BCM27 + 10k pullup

## Waveshare ESP32-S3-Touch-LCD-1.85

## SKU28514 · 360×360 TFT · USB serial face commands

## User-selected PCA9685 PWM controller

## 0x40 · 50Hz · channels0–3 · 3.3V logic only

## Four inventory Miuzei DS3218MG servos

## Yaw / shoulder / elbow / wrist · separate fused6V feeds

## Adafruit3369 USB speaker / espeak-ng

## Adafruit5626 PCA9548 mux · 0x70

## TCA9548A-compatible · 3.3V upstream logic

## Five Adafruit3967 VL53L1X · 0x29 each

## Ports0–4: front / front-left / rear-left

## rear-right / front-right · all inside pedestal wall

## 74AHCT125 / two 3.3V → 5V channels

## DIP2→3 RGB · DIP5→6 white · 330Ω each output

### VCC5V on14 · GND7 · enable1 and4 to GND

## Two independent light rings

## Outer60RGB ≤20% · inner24RGBW: RGB0 / W≤192

### 1000µF across each ring supply · last outer DOUT open

## Two external supplies

## Official Pi5.1V / 3A → Pi USB-C

## Mean Well12V / 15A → DC only
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

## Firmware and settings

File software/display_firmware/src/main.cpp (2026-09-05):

// LUMA face coprocessor. Exact board: Waveshare ESP32-S3-Touch-LCD-1.85,
// SKU28514, no B/C suffix. The Pi4 controls all behaviors over USB serial.
#include <Arduino.h>
#include <Wire.h>
#include <Arduino_GFX_Library.h>
#include <math.h>
#include <driver/spi_master.h>
#include "panel_init.h"

Arduino_DataBus *bus = nullptr;
Arduino_GFX *lcd = nullptr;
Arduino_Canvas *face = nullptr;
String expression = "idle";
uint32_t expressionStart = 0, lastHost = 0, lastFrame = 0;
char input[64];
size_t inputLength = 0;
bool overflow = false;

bool expanderWrite(uint8_t reg, uint8_t value) {
  Wire.beginTransmission(0x20);
  Wire.write(reg); Wire.write(value);
  return Wire.endTransmission() == 0;
}

int panelVariant() {
  // Read ID at the vendor's conservative5MHz before Arduino_GFX takes the bus.
  // Commands are32bits, opcode0x0B / register0x04 / trailing dummy byte.
  spi_bus_config_t cfg = {};
  cfg.mosi_io_num=46; cfg.miso_io_num=45; cfg.sclk_io_num=40;
  cfg.quadwp_io_num=42; cfg.quadhd_io_num=41;
  cfg.data4_io_num=-1; cfg.data5_io_num=-1; cfg.data6_io_num=-1; cfg.data7_io_num=-1;
  cfg.max_transfer_sz=64;
  if (spi_bus_initialize(SPI2_HOST,&cfg,SPI_DMA_CH_AUTO)!=ESP_OK) return -1;
  spi_device_interface_config_t dev = {};
  dev.command_bits=8; dev.address_bits=24;
  dev.clock_speed_hz=5000000; dev.spics_io_num=21;
  dev.flags=SPI_DEVICE_HALFDUPLEX; dev.queue_size=1;
  spi_device_handle_t handle;
  if (spi_bus_add_device(SPI2_HOST,&dev,&handle)!=ESP_OK) {
    spi_bus_free(SPI2_HOST); return -1;
  }
  spi_transaction_t transaction = {};
  transaction.cmd=0x0B; transaction.addr=0x000400; transaction.rxlength=32;
  transaction.flags=SPI_TRANS_USE_RXDATA;
  esp_err_t status=spi_device_polling_transmit(handle,&transaction);
  uint8_t *id=transaction.rx_data;
  Serial.printf("PANEL %02X %02X %02X %02X\n",id[0],id[1],id[2],id[3]);
  int variant = -1;
  if(status==ESP_OK && id[0]==0 && id[2]==0x7F && id[3]==0x7F) {
    if(id[1]==0x7F) variant=0;
    if(id[1]==0x02) variant=1;
  }
  spi_bus_remove_device(handle);
  spi_bus_free(SPI2_HOST);
  return variant;
}

void acceptLine() {
  input[inputLength] = 0;
  if (strcmp(input, "PING") == 0) {
    lastHost = millis(); Serial.println("PONG"); return;
  }
  if (strncmp(input, "FACE ", 5) == 0) {
    String next = String(input + 5);
    if (next == "idle" || next == "wink" || next == "hi" || next == "happy" || next == "fault") {
      if (next != expression) { expression = next; expressionStart = millis(); }
      lastHost = millis(); Serial.print("OK "); Serial.println(expression); return;
    }
  }
  Serial.println("ERR command");
}

void readHost() {
  while (Serial.available()) {
    char ch = static_cast<char>(Serial.read());
    if (ch == '\r') continue;
    if (ch == '\n') {
      if (!overflow) acceptLine(); else Serial.println("ERR length");
      inputLength = 0; overflow = false;
    } else if (inputLength < sizeof(input)-1) {
      input[inputLength++] = ch;
    } else {
      overflow = true;
    }
  }
}

void strokeArc(int cx, int cy, int rx, int ry, float start, float end, int width, uint16_t color) {
  for (float a=start; a<=end; a+=0.03f)
    face->fillCircle(cx+rx*cosf(a), cy+ry*sinf(a), width, color);
}

void paint() {
  const uint16_t black = 0x0000, cyan = 0x67DF, blush = 0xC1EF;
  float t = (millis()-expressionStart)/1000.f;
  bool offline = millis()-lastHost>1500;
  face->fillScreen(black);
  uint16_t color = (expression == "fault" || offline) ? 0xFC60 : cyan;
  if (expression == "fault" || offline) {
    face->fillRoundRect(90,136,60,12,6,color);
    face->fillRoundRect(210,136,60,12,6,color);
    face->fillRoundRect(150,235,60,9,4,color);
    face->setTextColor(color); face->setTextSize(2); face->setCursor(120,285);
    face->print(offline ? "WAITING" : "PAUSED");
  } else {
    bool wink = expression=="wink" && fmodf(t,3.f)>0.65f && fmodf(t,3.f)<1.45f;
    bool blink = expression=="idle" && (millis()%5200)>5050;
    bool happy = expression=="happy";
    if (happy) {
      strokeArc(119,155,32,22,3.25,6.15,6,color);
      strokeArc(241,155,32,22,3.25,6.15,6,color);
    } else {
      if (blink) face->fillRoundRect(92,146,54,10,5,color);
      else face->fillRoundRect(95,107,48,74,22,color);
      if (wink || blink) face->fillRoundRect(214,146,54,10,5,color);
      else face->fillRoundRect(217,107,48,74,22,color);
    }
    face->fillCircle(77,207,13,blush); face->fillCircle(283,207,13,blush);
    if (expression=="hi") {
      int opening = 8 + int(12*(0.5f+0.5f*sinf(t*12)));
      face->fillCircle(180,232,opening,color);
      face->setTextColor(color); face->setTextSize(3); face->setCursor(155,289); face->print("Hi!");
    } else {
      strokeArc(180,205,51,happy?45:30,0.15,2.99,6,color);
    }
  }
  face->flush();
}

void setup() {
  Serial.begin(115200);
  Wire.begin(11,10);
  Wire.setClock(100000);
  // TCA9554 EXIO1=P0 touch reset, EXIO2=P1 LCD reset, EXIO3=P2 SD CS.
  // Leave EXIO4..8 as inputs and deselect unused SD.
  expanderWrite(1,0x07);
  if (!expanderWrite(3,0xF8)) {
    Serial.println("ERR expander");
    while (true) delay(100);
  }
  expanderWrite(1,0x05); delay(120);
  expanderWrite(1,0x07); delay(120);
  int variant=panelVariant();
  if(variant<0) {
    Serial.println("ERR unknown panel ID");
    while(true) delay(100);
  }
  bus = new Arduino_ESP32QSPI(21,40,46,45,42,41);
  const uint8_t *init = variant ? luma_panel_new : luma_panel_old;
  size_t initSize = variant ? sizeof(luma_panel_new) : sizeof(luma_panel_old);
  lcd = new Arduino_ST77916(bus,GFX_NOT_DEFINED,0,true,360,360,0,0,0,0,init,initSize);
  face = new Arduino_Canvas(360,360,lcd);
  pinMode(5,OUTPUT); digitalWrite(5,HIGH);
  if (!face->begin()) {
    Serial.println("ERR display");
    while (true) delay(100);
  }
  lastHost=millis();
  Serial.println("READY LUMA1");
}

void loop() {
  readHost();
  if (millis()-lastFrame >= 40) { lastFrame=millis(); paint(); }
  delay(1);
}

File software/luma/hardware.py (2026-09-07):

"""Raspberry Pi 4 adapters. Importing behavior code needs no hardware packages."""
import subprocess
import time
from contextlib import ExitStack
from .control import Reading, SENSOR_NAMES, LIMITS
from .servo_pwm import (
    MAX_PULSE_US, MIN_PULSE_US, US_PER_DEGREE,
    ServoError, ServoPwm, angles_to_pulses, validate_servo_channels,
)


def validate_config(config, arm):
    for field in ("neutral_pulse_us", "joint_signs", "servo_channels"):
        if len(config.get(field, [])) != 4:
            raise ValueError(f"{field} must contain four values")
    if any(type(v) is not int for v in config["neutral_pulse_us"]):
        raise ValueError("neutral pulse widths must be integers")
    for neutral, limit in zip(config["neutral_pulse_us"], LIMITS):
        margin = (limit + 4) * US_PER_DEGREE
        if neutral - margin < MIN_PULSE_US or neutral + margin > MAX_PULSE_US:
            raise ValueError("neutral pulse widths must leave room for limited motion")
    if any(v not in (-1, 1) for v in config["joint_signs"]):
        raise ValueError("joint_signs must be +1 or -1")
    validate_servo_channels(config["servo_channels"])
    if type(config.get("pca9685_address")) is not int or not 0x08 <= config["pca9685_address"] <= 0x77:
        raise ValueError("pca9685_address must be a usable 7-bit I2C address")
    if not 0 <= config["outer_brightness"] <= 0.20:
        raise ValueError("Outer RGB brightness is limited to 20%")
    if not 0 <= config["inner_brightness"] <= 1.0:
        raise ValueError("Inner white brightness must be between0 and1")
    if arm and config.get("calibrated") is not True:
        raise ValueError("Complete unloaded joint calibration before setting calibrated=true")
    display_kind = config.get("display_kind", "usb_serial")
    if display_kind not in ("usb_serial", "dsi"):
        raise ValueError(f"display_kind must be usb_serial or dsi, got {display_kind!r}")
    if display_kind == "usb_serial" and "SET_TO_" in config["display_port"]:
        raise ValueError("Set display_port to the actual /dev/serial/by-id device")


class Ranging:
    def __init__(self, i2c=None):
        import board, adafruit_tca9548a, adafruit_vl53l1x
        self.i2c = i2c or board.I2C()
        self.owns_i2c = i2c is None
        mux = adafruit_tca9548a.TCA9548A(self.i2c, address=0x70)
        self.devices = []
        try:
            for channel in range(5):
                sensor = adafruit_vl53l1x.VL53L1X(mux[channel])
                self.devices.append(sensor)
                sensor.distance_mode = 1
                sensor.timing_budget = 33
                sensor.stop_ranging()
        except BaseException:
            self.close()
            raise
        self.samples = {}
        self.active = 0
        self.started = None

    def poll(self, now):
        # One emitter ranges at a time: the mux alone cannot prevent optical crosstalk.
        sensor = self.devices[self.active]
        name = SENSOR_NAMES[self.active]
        if self.started is None:
            sensor.start_ranging()
            self.started = now
        elif sensor.data_ready:
            cm = sensor.distance
            self.samples[name] = Reading(None if cm is None else cm * 10.0, now)
            sensor.clear_interrupt()
            sensor.stop_ranging()
            self.active = (self.active + 1) % 5
            self.started = None
        elif now - self.started > 0.12:
            self.samples[name] = Reading(None, now)
            sensor.stop_ranging()
            self.active = (self.active + 1) % 5
            self.started = None
        return self.samples

    def close(self):
        for sensor in self.devices:
            try:
                sensor.stop_ranging()
            except OSError:
                pass
        if self.owns_i2c:
            self.i2c.deinit()


class Display:
    def __init__(self, port):
        import serial
        self.io = serial.Serial(port, 115200, timeout=0, write_timeout=0.05)
        self.last_rx = time.monotonic()
        self.seen_reply = False
        self.last_tx = -100.0
        self.face = None
        self.buffer = b""

    def update(self, now, face):
        pending = self.io.in_waiting
        if pending:
            self.buffer += self.io.read(min(pending, 512))
            while b"\n" in self.buffer:
                line, self.buffer = self.buffer.split(b"\n", 1)
                if line.strip() in (b"PONG", b"READY LUMA1") or line.startswith(b"OK "):
                    self.last_rx = now
                    self.seen_reply = True
            self.buffer = self.buffer[-256:]
        if face != self.face:
            self.io.write(f"FACE {face}\n".encode("ascii"))
            self.face = face
        if now - self.last_tx > 0.25:
            self.io.write(b"PING\n")
            self.last_tx = now
        return self.seen_reply and now - self.last_rx < 1.5

    def close(self):
        self.io.close()
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

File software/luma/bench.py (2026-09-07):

"""Focused hardware checks; servo output requires an explicit unloaded confirmation."""
import argparse
import json
import math
from pathlib import Path
import sys
import time

from .control import JOINT_NAMES, SCENES, SENSOR_NAMES
from .hardware import Display, Ranging
from .servo_pwm import MAX_PULSE_US, MIN_PULSE_US, ServoPwm


def duration(value):
    seconds = float(value)
    if not math.isfinite(seconds) or not 0 < seconds <= 600:
        raise argparse.ArgumentTypeError("seconds must be finite and between 0 and 600")
    return seconds


def servo_duration(value):
    seconds = float(value)
    if not math.isfinite(seconds) or not 0 < seconds <= 10:
        raise argparse.ArgumentTypeError("servo seconds must be finite and between0 and10")
    return seconds


def pulse_width(value):
    pulse = int(value)
    if not MIN_PULSE_US <= pulse <= MAX_PULSE_US:
        raise argparse.ArgumentTypeError("pulse must be between500 and2500us")
    return pulse


def sensor_snapshot(samples, now):
    result = {}
    for channel, name in enumerate(SENSOR_NAMES):
        reading = samples.get(name)
        mm, age, state = None, None, "missing"
        if reading is not None:
            age = now - reading.stamp
            if not math.isfinite(age) or not 0 <= age <= 0.65:
                state = "stale"
            elif reading.mm is None or not math.isfinite(reading.mm) or not 30 <= reading.mm <= 4000:
                state = "invalid"
            else:
                mm = round(reading.mm, 1)
                state = "near" if mm < 100 else "ok"
        result[name] = {
            "mux_channel": channel,
            "mm": mm,
            "age_s": round(age, 3) if age is not None and math.isfinite(age) else None,
            "state": state,
        }
    return result


def sensors(seconds):
    ranging = Ranging()
    try:
        start = time.monotonic()
        next_report = start
        samples = {}
        while (now := time.monotonic()) - start < seconds:
            samples = ranging.poll(now)
            if now >= next_report:
                print(json.dumps({"t": round(now - start, 2), "sensors": sensor_snapshot(samples, now)}), flush=True)
                next_report = now + 0.25
            time.sleep(0.005)
        snapshot = sensor_snapshot(samples, time.monotonic())
        passed = all(r["state"] in ("ok", "near") for r in snapshot.values())
        print(json.dumps({"check": "sensors", "passed": passed, "sensors": snapshot}), flush=True)
        # A near range proves communication but is an obstruction in armed operation.
        return 0 if passed else 1
    finally:
        ranging.close()


def display(port, seconds, scene, kind="usb_serial"):
    if kind == "dsi":
        from .face import DsiDisplay
        screen = DsiDisplay()
    else:
        screen = Display(port)
    try:
        start = time.monotonic()
        next_report = start
        healthy = False
        while (now := time.monotonic()) - start < seconds:
            face = SCENES[int((now - start) / 2) % len(SCENES)] if scene == "all" else scene
            healthy = screen.update(now, face)
            if now >= next_report:
                print(json.dumps({"t": round(now - start, 2), "face": face, "heartbeat": healthy}), flush=True)
                next_report = now + 0.5
            time.sleep(0.02)
        print(json.dumps({"check": "display", "passed": healthy}), flush=True)
        return 0 if healthy else 1
    finally:
        screen.close()


def servo(config_path, joint, pulse_us, seconds):
    import board
    config = json.loads(config_path.read_text())
    i2c = board.I2C()
    controller = None
    try:
        controller = ServoPwm(i2c, config["servo_channels"], config["pca9685_address"])
        index = JOINT_NAMES.index(joint)
        controller.move_one(index, pulse_us)
        print(json.dumps({"check":"servo","joint":joint,"channel":config["servo_channels"][index],
                          "pulse_us":pulse_us,"seconds":seconds,"warning":"unloaded output active"}),flush=True)
        time.sleep(seconds)
        return 0
    finally:
        try:
            if controller is not None:
                controller.disable()
        finally:
            try:
                if controller is not None:
                    controller.close()
            finally:
                i2c.deinit()


def build_parser():
    parser = argparse.ArgumentParser(description=__doc__)
    commands = parser.add_subparsers(dest="command", required=True)
    sensor_parser = commands.add_parser("sensors", help="Poll all five mux channels without motors or LED rings")
    sensor_parser.add_argument("--seconds", type=duration, default=10.0)
    display_parser = commands.add_parser("display", help="Check display heartbeat and request animated faces")
    display_parser.add_argument("--port", default=None,
        help="Actual USB serial device; /dev/serial/by-id/... on Pi. Required unless --kind dsi")
    display_parser.add_argument("--kind", choices=("usb_serial", "dsi"), default="usb_serial",
        help="usb_serial talks to the ESP32 face board; dsi renders locally on the Waveshare panel")
    display_parser.add_argument("--seconds", type=duration, default=10.0)
    display_parser.add_argument("--scene", choices=("all", *SCENES, "fault"), default="all")
    servo_parser = commands.add_parser("servo", help="Center one unloaded DS3218MG through the PCA9685")
    servo_parser.add_argument("--config", type=Path,
        default=Path(__file__).resolve().parents[1]/"config.json")
    servo_parser.add_argument("--joint", choices=JOINT_NAMES, required=True)
    servo_parser.add_argument("--pulse-us", type=pulse_width, default=1500)
    servo_parser.add_argument("--seconds", type=servo_duration, default=2.0)
    servo_parser.add_argument("--confirm-unloaded", action="store_true",
        help="required: servo horn is disconnected from the arm and the motor stop is in reach")
    return parser


def main(argv=None):
    parser = build_parser()
    args = parser.parse_args(argv)
    if args.command == "display" and args.kind == "usb_serial" and not args.port:
        parser.error("--port is required when --kind usb_serial")
    if args.command == "servo" and not args.confirm_unloaded:
        parser.error("servo check requires --confirm-unloaded")
    try:
        if args.command == "sensors":
            return sensors(args.seconds)
        if args.command == "display":
            return display(args.port, args.seconds, args.scene, args.kind)
        return servo(args.config, args.joint, args.pulse_us, args.seconds)
    except KeyboardInterrupt:
        return 130
    except Exception as exc:
        print(f"Bench check failed: {type(exc).__name__}: {exc}", file=sys.stderr)
        return 1


if __name__ == "__main__":
    raise SystemExit(main())

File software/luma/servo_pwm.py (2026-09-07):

"""PCA9685 control for four Miuzei DS3218MG 270-degree position servos.

The PCA9685 confirms only controller communication. The servos provide no
position, load, current, or temperature telemetry.
"""
import math


SERVO_COUNT = 4
PWM_FREQUENCY_HZ = 50
MIN_PULSE_US = 500
MAX_PULSE_US = 2500
ANGLE_SPAN_DEG = 270.0
US_PER_DEGREE = (MAX_PULSE_US - MIN_PULSE_US) / ANGLE_SPAN_DEG


class ServoError(RuntimeError):
    pass


def validate_servo_channels(channels):
    if (not isinstance(channels, (list, tuple)) or len(channels) != SERVO_COUNT
            or len(set(channels)) != SERVO_COUNT
            or any(type(channel) is not int or not 0 <= channel < 16 for channel in channels)):
        raise ValueError("servo channels must be four unique PCA9685 channels")
    return tuple(channels)


def pulse_to_duty_cycle(pulse_us):
    if isinstance(pulse_us, bool) or not isinstance(pulse_us, (int, float)):
        raise ValueError("pulse width must be a number")
    if not math.isfinite(pulse_us) or not MIN_PULSE_US <= pulse_us <= MAX_PULSE_US:
        raise ValueError("pulse width outside DS3218 range")
    return round(pulse_us * PWM_FREQUENCY_HZ * 65535 / 1_000_000)


def angles_to_pulses(neutral_pulse_us, joint_signs, angles):
    if not all(len(values) == SERVO_COUNT for values in (neutral_pulse_us, joint_signs, angles)):
        raise ValueError("expected four servo values")
    pulses = [round(neutral + sign * angle * US_PER_DEGREE)
              for neutral, sign, angle in zip(neutral_pulse_us, joint_signs, angles)]
    if any(not MIN_PULSE_US <= pulse <= MAX_PULSE_US for pulse in pulses):
        raise ValueError("servo target outside DS3218 pulse range")
    return pulses


class ServoPwm:
    def __init__(self, i2c, channels, address=0x40):
        from adafruit_pca9685 import PCA9685
        self.channels = validate_servo_channels(channels)
        self.pca = None
        try:
            self.pca = PCA9685(i2c, address=address)
            self.pca.frequency = PWM_FREQUENCY_HZ
            self.disable()
        except (OSError, ValueError, ServoError) as error:
            if self.pca is not None:
                self.pca.deinit()
            raise ServoError(f"PCA9685 initialization failed: {error}") from error

    def move(self, pulses):
        if len(pulses) != SERVO_COUNT:
            raise ValueError("expected four servo pulse widths")
        duties = [pulse_to_duty_cycle(pulse) for pulse in pulses]
        try:
            for channel, duty in zip(self.channels, duties):
                self.pca.channels[channel].duty_cycle = duty
        except OSError as error:
            raise ServoError(f"PCA9685 write failed: {error}") from error

    def move_one(self, joint_index, pulse_us):
        if type(joint_index) is not int or not 0 <= joint_index < SERVO_COUNT:
            raise ValueError("joint index must be0 through3")
        duty = pulse_to_duty_cycle(pulse_us)
        self.disable()
        try:
            self.pca.channels[self.channels[joint_index]].duty_cycle = duty
        except OSError as error:
            raise ServoError(f"PCA9685 write failed: {error}") from error

    def disable(self):
        try:
            for channel in self.channels:
                self.pca.channels[channel].duty_cycle = 0
        except OSError as error:
            raise ServoError(f"PCA9685 disable failed: {error}") from error

    def healthy(self):
        try:
            mode = int(self.pca.mode1_reg)
            frequency = float(self.pca.frequency)
            return bool(mode & 0x20) and abs(frequency - PWM_FREQUENCY_HZ) < 1.0
        except (OSError, TypeError, ValueError):
            return False

    def close(self):
        self.pca.deinit()

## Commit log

2026-09-05 LUMA revision A baseline before revision B (enclosed arms, optional 4-inch DSI head)
    [LUMA_Print_Schedule.csv, LUMA_Purchased_Parts.csv, assembled_reference_DO_NOT_PRINT.stl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]
2026-09-05 Revision B: enclosed arm links, optional 4-inch DSI head CAD, checks and docs
    [LUMA_Print_Schedule.csv, LUMA_Purchased_Parts.csv, assembled_reference_DO_NOT_PRINT.stl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]
2026-09-05 Revision B deliverables: renders, films, drawings, manual, verification and package
    [luma_exploded.blend]
2026-09-07 Plan revision C pedestal sensors and PWM servos
2026-09-07 Move sensors to pedestal and fit DS3218 joints
    [assembled_reference_DO_NOT_PRINT.stl, assembled_reference_dsi_DO_NOT_PRINT.stl, assembly.scad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]
2026-09-07 Control DS3218 servos through PCA9685
2026-09-07 Document PCA9685 power and pedestal sensor build
    [LUMA_Print_Schedule.csv, LUMA_Purchased_Parts.csv, assembled_reference_DO_NOT_PRINT.stl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]
2026-09-07 Regenerate revision C project deliverables
    [assembled_reference_DO_NOT_PRINT.stl, assembled_reference_dsi_DO_NOT_PRINT.stl, base_lid.stl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]
2026-09-07 Fix revision C review findings
    [LUMA_Purchased_Parts.csv, bom_electronics.csv]
2026-09-08 Document Raspberry Pi 4 AI options
